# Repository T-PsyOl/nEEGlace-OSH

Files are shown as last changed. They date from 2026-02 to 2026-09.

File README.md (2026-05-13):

# nEEGlace-OpenHardware

nEEGlace open hardware
nEEGlace is an open hardware platform for studying neural activity in everyday
environments. It is designed to enable long-term, wearable EEG recordings
combined with rich contextual data, such as binaural audio, while remaining
compact, reproducible, and extensible.

The project is developed at the Translational Psychology Lab,
at the Department of Psychology at the Carl von Ossietzky Universität Oldenburg.

## Motivation

Understanding brain activity outside the laboratory is essential for studying
natural cognition, perception, and behavior. However, conventional EEG systems
are typically bulky, restrictive, and optimized for short, controlled
experiments. As a result, they are poorly suited for long-term or
ecologically valid recordings and often lack information about the sensory and
environmental context in which neural signals are recorded.

nEEGlace addresses these limitations by integrating ear-EEG with additional
contextual sensors into a neck-worn, wearable system that can be used in
real-world settings.

## Scientific Background

nEEGlace-OpenHardware builds on several stages of previous work on mobile,
neck-worn EEG systems for studying brain activity beyond the laboratory.

An early precursor was used in a long-term mobile ear-EEG study on auditory
attention in everyday life. In that study, a mobile EEG amplifier was attached
to headphones worn around the neck, which were also used for sound presentation.
Participants wore the setup for several hours while performing auditory oddball
tasks in the laboratory and during normal office routines. This work showed that
long-term mobile EEG recordings can be used to study auditory processing in
everyday settings.
The study can be found here:

[Hölle, D., Meekes, J., & Bleichner, M. G. (2021). Mobile ear-EEG to study
auditory attention in everyday life. *Behavior Research Methods*, 53,
2025–2036.](https://doi.org/10.3758/s13428-021-01538-0)

Based on this experience, the original nEEGlace system was developed as a more
integrated neck-worn platform. It combined a commercial, research-grade EEG
amplifier with a commercial neck speaker, creating a compact system for mobile
EEG recordings with integrated sound presentation and contextual audio
recording.

The original nEEGlace project is documented in the previous repository:

[https://github.com/T-PsyOl/neeglace](https://github.com/T-PsyOl/neeglace)

The associated hardware metapaper was published in the *Journal of Open
Hardware*:

[Bleichner, M. G., & Emkes, R. (2020). Building an Ear-EEG System by Hacking a
Commercial Neck Speaker and a Commercial EEG Amplifier to Record Brain Activity
Beyond the Lab. *Journal of Open Hardware*, 4(1).](https://doi.org/10.5334/joh.25)

This nEEGlace version was subsequently used in a study on smartphone-based
ear-EEG for investigating sound processing in everyday life. In that work,
participants were equipped with the nEEGlace, a smartphone-based recording setup, and microphones for recording
the acoustic environment. The study demonstrated how mobile EEG recordings can
be combined with contextual sound information to investigate neural responses
to sounds in more naturalistic conditions.

The study is described here:

[Hölle, D., & Bleichner, M. G. (2023). Smartphone-based
ear-electroencephalography to study sound processing in everyday life.
*European Journal of Neuroscience*, 58(7), 3671–3685.](https://doi.org/10.1111/ejn.16124)

The current nEEGlace-OpenHardware platform continues this line of work. Whereas
the earlier systems relied on adapting and integrating commercial components,
nEEGlace-OpenHardware is designed as a reproducible, modular, and extensible
open-hardware platform. It retains the central scientific aim of recording
neural activity together with contextual information in everyday environments,
while making the system easier to document, reproduce, modify, and further
develop.

## System Overview
nEEGlace is designed around a modular, 3D-printable casing that can be worn around
the neck. The casing houses the core components required for mobile EEG and
contextual audio recording and provides a reproducible mechanical platform for
integrating different hardware configurations.

The system includes:

- **A neck-worn casing** that can be 3D printed and adapted to house different
  hardware components and configurations.
- **Electrode connectors** for connecting ear-EEG electrodes, such as cEEGrids,
  or other EEG electrode arrangements.
- **An EEG acquisition system** for recording neural activity during mobile
  measurements.
- **An audio processing board** for real-time audio processing, event
  extraction, and event injection into the EEG data stream.
- **Binaural microphones** for recording the acoustic environment from the
  wearer’s perspective.
- **A battery unit** that powers all components for several hours of mobile
  operation.

The system is modular by design. Components such as the EEG system, audio board,
microphones, battery unit, connectors, and casing parts can be modified,
replaced, or reconfigured without redesigning the full platform. This allows
nEEGlace to serve as a general neck-worn hardware platform for mobile
neurophysiology and context-aware sensing, rather than as a fixed device tied to
one specific hardware setup.

## Repository Structure

This repository contains all components required to build, program, and use the
nEEGlace system:
- assets/ Media files, figures, and illustrations
- docs/ Background documentation and design rationale
- firmware/ Low-level firmware for embedded components
- hardware/ Hardware documentation (electronics, BMS, casing, wiring)
- manufacturing/ Manufacturing files and production-related information
- software/ User-facing software, analysis tools, and utilities
- test/ Hardware and software tests and validation scripts

Each folder contains its own README with more detailed documentation.

## Design Principles

nEEGlace follows a small set of guiding principles:

- **Open hardware**: schematics, layouts, and designs are shared
- **Modularity**: hardware and software components are loosely coupled
- **Wearability**: suitable for long-term use in everyday environments
- **Context awareness**: neural data is recorded together with relevant
  environmental information

## Project Status

nEEGlace is an active research and development project.
The hardware and software described here reflect the current prototype and may
evolve over time. Contributions, feedback, and replication efforts are welcome.

For details on specific components, please start with the corresponding
subfolder.

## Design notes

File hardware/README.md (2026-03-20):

# nEEGlace Hardware
This directory documents the complete hardware setup of the nEEGlace system.

The hardware integrates EEG acquisition, high-quality audio recording,
real-time processing, and battery-powered operation into a single wearable
device.

## System Overview

The nEEGlace hardware is built around the following core components:

- [Bela GEM Stereo](https://eu.shop.bela.io/products/bela-gem-stereo) for real-time audio and control
   - We originally used the Bela Mini; however, as it has been discontinued, we are transitioning to the Bela GEM Stereo.
- [OpenBCI Cyton (8-channel)](https://shop.openbci.com/products/cyton-biosensing-board-8-channel) or [Cyton + Daisy (16-channel)](https://shop.openbci.com/products/cyton-daisy-biosensing-boards-16-channel) for (ear)-EEG
- [Roland CS-10EM binaural microphones](https://proav.roland.com/de/products/proav_cs-10em/) for stereo audio
- **Battery Management System (BMS)** and rechargeable battery
- **Custom Bela Cape** for electrical integration
- **Wearable casing** and internal wiring

## Directory Structure

hardware/
├── BMS/
│   └── README.md
├── cape/
│   └── README.md
├── casing/
│   └── README.md
├── wiring/
│   └── README.md
└── README.md  ← you are here

Each subfolder documents one hardware module and its role in the overall system.

## Required Hardware Components

### 1. Processing and Control
- **Bela Gem Stereo**
  - Executes real-time audio and data acquisition code
  - Acts as the central control unit

- **Custom Bela Cape**
  - Interfaces Bela Mini with:
    - OpenBCI EEG amplifier
    - Roland CS-10EM microphones
    - Power system
  - Provides signal routing and mechanical mounting

### 2. EEG Acquisition
- **OpenBCI Cyton Biosensing Board (8-channel)**  
  *or*  
- **OpenBCI Cyton + Daisy Biosensing Boards (16-channel)**

- **EEG electrodes**
  - EEG electrodes
  - OpenBCI-compatible connectors and cables

### 3. Audio Acquisition
- **Roland CS-10EM binaural microphones**
  - In-ear stereo microphones
  - Connected to Bela Mini audio inputs

- **Audio cabling**
  - Stereo microphone cables

### 4. Power System
- **Rechargeable battery**
  - LiPo

- **Battery Management System (BMS)**
  - Battery charging
  - Electrical protection
  - Power distribution to Bela and peripherals

### 5. Wiring and Interconnection

### 6. Mechanical Components
- **nEEGlace casing**
  - Houses all electronic components
  - Designed for wearable, everyday use
- Fasteners and mounting elements

## Design Principles

The nEEGlace hardware follows these principles:

- **Open hardware**: all designs are shared and documented
- **Modularity**: individual components can be replaced or extended
- **Low-noise design**: separate EEG and audio signal paths
- **Wearability**: suitable for long-term, real-world recordings

## Status

This documentation reflects the current nEEGlace prototype.
Hardware components and interfaces may evolve as the project progresses.
Each submodule README documents its current state and known limitations.

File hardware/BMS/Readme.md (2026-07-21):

# <ins>nEEGlace – Battery Management System (BMS)</ins>

---

## Table of Contents

- [Overview](#overview)
- [Repository Structure & File Guide](#repository-structure--file-guide)
- [Hardware Overview](#hardware-overview)
- [Component Reference](#component-reference)
  - [Battery Connector](#battery-connector)
  - [HiLetgo Module Connectors](#hiletgo-module-connectors)
  - [Power Switch (S)](#power-switch-s)
  - [Charge-Detect MOSFET (SSI2301CDS-T1-E3)](#charge-detect-mosfet-ssi2301cds-t1-e3)
  - [LDO Regulator (MCP1700T-3302)](#ldo-regulator-mcp1700t-3302)
  - [Bela 5V Output Connector](#bela-5v-output-connector)
  - [3.3V OBCI Output Connector](#33v-obci-output-connector)
  - [Mic 3.3V Output Connector](#mic-33v-output-connector)
- [Power Architecture](#power-architecture)
- [Charge-Safety Logic — Why the MOSFET Matters](#charge-safety-logic--why-the-mosfet-matters)
- [Signal Routing & Design Rationale](#signal-routing--design-rationale)
- [Connector Pinouts](#connector-pinouts)
- [Layer Stack](#layer-stack)
- [Use Cases](#use-cases)
---

## Overview

The **nEEGlace BMS** is a single-layer-routed, two-layer PCB that sits between a single-cell Li-ion/Li-Po battery, a **HiLetgo** charge/boost breakout module, and the downstream **Bela** + **OpenBCI** electronics on the nEEGlace headset. It provides:

- **Battery input** with a physical power switch
- **Charge-state detection** that automatically disconnects the downstream system while the battery is charging (prevents brown-outs, ground loops, and noisy USB power from reaching sensitive analog inputs)
- **Regulated 5V output** to power the Bela cape directly from the HiLetgo module
- **Regulated 3.3V output** (via onboard LDO) for the OpenBCI board and the microphone bias input on the Bela Cape

This board is designed for:
- Portable / wearable EEG data acquisition (nEEGlace headset)
- Powering a Bela Cape + Bela embedded audio platform from battery
-  Safe co-operation with OpenBCI boards on a shared battery rail
-  Automatic charge-safe shutdown — no manual power cycling required when charging

---

## Repository Structure & File Guide

```
nEEGlace BMS/
│
├── Assembly files/                    # Production-ready fabrication package
│   └── PickAndPlace_PCB_nEEGlace_BMS_* #   Centroid/pick-and-place file for PCBA
│
├── Datasheets/                        # Component datasheets (LDO, MOSFET, HiLetgo, etc.)
│
├── BMS_PCB_Connections.pdf            # Wiring / interconnection reference
│                                      #   → How the BMS connects to Battery,
│                                      #     HiLetgo, Bela, and OpenBCI
│
├── Gerber_nEEGlace_BMS_PCB.zip         # Gerber + Excellon drill files
│                                      #   → Send to any PCB fab to order boards
│
├── OBJ_PCB_nEEGlace_BMS.zip            # 3D mechanical model (OBJ format)
│                                      #   → Use for enclosure design and
│                                      #     mechanical clearance verification
│
├── PCB_nEEGlace_BMS.json              # KiCad PCB layout (machine-readable)
│
├── PCB_nEEGlace_BMS.pdf               # Printable PCB layout (all layers)
│
├── nEEGlace_BMS_PCB.png               # Rendered 3D top-view image of the PCB
│
├── Schematic_nEEGlace_BMS.pdf          # Complete circuit schematic
│                                      #   → Primary reference for signal tracing,
│                                      #     net names, and component values
│
├── odb++_pcb_BMS.tgz                  # ODB++ manufacturing data (alternative to Gerbers)
│
└── Readme.md                          # This file
```

### Quick-Reference: Which File Do I Need?

| Goal | File to Use |
|---|---|
| Order bare PCBs | `Gerber_nEEGlace_BMS_PCB.zip` or `odb++_pcb_BMS.tgz` |
| Order fully assembled PCBs (PCBA) | `Assembly files/` folder |
| Understand the circuit | `Schematic_nEEGlace_BMS.pdf` |
| Wire the board into the nEEGlace system | `BMS_PCB_Connections.pdf` |
| Design an enclosure | `OBJ_PCB_nEEGlace_BMS.zip` |
| Visual reference during assembly | `nEEGlace_BMS_PCB.png` / `PCB_nEEGlace_BMS.pdf` |
| Source replacement parts | `Datasheets/` folder |

---

## Hardware Overview
Screenshot 2026-06-23 at 10 32 29 PM

**Board form factor:** Small wearable-friendly form factor for the nEEGlace headset
**Layer count:** 2 (signal + ground plane)
**Key active components:** 1× LDO regulator, 1× N-channel MOSFET, 1× SPDT/SPST power switch

---

## Component Reference

## <ins>Hardware Components</ins>

1. [3.7 V 6000 mAh Li-ion battery](https://www.reichelt.de/de/de/shop/produkt/ersatzakku_jbl_charge_li-po_6000_mah-248010)
2. [HiLetGo USB-C / USB-A charging and discharging board](https://www.amazon.de/HiLetgo-Discharging-Integrated-Interface-Compatible/dp/B0CDWT9295)
3. [MCP1700-330E low-dropout regulator (3.3 V)](https://www.mouser.de/ProductDetail/Microchip-Technology/MCP1700T-3302E-MB?qs=WWgnj3qycfnlJJhwyn%2Fifw%3D%3D)
4. [Schottky Diode(for unidirectional charge routing)](https://www.mouser.de/ProductDetail/Rectron/SR340-T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)
5. [MOSFET(for safety load-switching)](https://www.mouser.de/ProductDetail/Vishay-Semiconductors/SI2301CDS-T1-E3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)
6. 100 kΩ and 10 kΩ resistors (supporting the MOSFET circuit)
7. Decoupling capacitor on 5 V rail- 10u and 100uF.
8. Custom two-layer PCB
9. Ground vias for noise reduction
10. Through-hole pads for power connections (no pin headers)
11. [Slider switch](https://www.reichelt.com/de/en/shop/product/slide_switch_straight_pitch_2_54_1_x_on_off_on-105710)
12. [Cables](https://www.reichelt.com/de/en/shop/product/copper_wire_0_5mm_10m_black-404600)

> A compact battery management and power-distribution board for the **nEEGlace** wearable EEG system, providing charge-safe power switching, 5V regulation via a HiLetgo boost/charge module, and 3.3V LDO regulation for OpenBCI and Bela Cape microphone inputs.

### Battery Connector

- **Location:** Bottom-left of the board, labelled `Battery`
- **Type:** 2-pin connector (JST-style)
- **Signals:** Battery (+), Battery (−) / GND
- **Function:** Main single-cell Li-ion/Li-Po input to the system

The battery feeds the **HiLetgo** module through the power switch, and is also the source that gets recharged when the HiLetgo module is connected to USB-C.

---

### HiLetgo Module Connectors

There are **two connectors** dedicated to the HiLetgo charge/boost breakout module:

| Connector | Location | Function |
|---|---|---|
| `HiLetgo` | Right edge, lower | Carries raw battery (+/−) to the HiLetgo module's battery terminal |
| `HiLetgo 5V` | Right edge, middle | Returns the HiLetgo module's regulated **5V output** back onto the BMS board |

**Design rationale:** The HiLetgo module performs two jobs depending on its USB-C state:
- **Battery present, no USB-C:** boosts/regulates the battery voltage to a constant 5V output
- **USB-C connected:** charges the battery, while still passing 5V through if powered

Because the same 5V output pin is active in both states, the BMS must distinguish *which* state is active before letting that 5V propagate downstream — this is the job of the MOSFET (see below).

---

### Power Switch (S)

- **Location:** Centre of the board, labelled `Switch`
- **Type:** Through-hole 6-pin (likely SPDT slide or tactile latching) switch
- **Function:** Main system on/off control

When closed, the switch connects the battery to the HiLetgo module's battery input, enabling the boost/regulation path. When open, the entire downstream system (Bela, OpenBCI, mic bias) is unpowered regardless of charge state.

---

### Charge-Detect MOSFET (SSI2301CDS-T1-E3)

- **Location:** Centre-left, labelled `MOSFET`, package SOT-23-3P
- **Part:** SSI2301CDS-T1-E3 — N-channel logic-level MOSFET
- **Function:** Automatic charge-state power gating

```
HiLetgo 5V ──┬── [10kΩ] ──┐
             │            ├──► Gate (charge-detect node)
             └── [100kΩ] ─┘
                            │
                          MOSFET (G-D-S)
                            │
                  Drain ──► to LDO input / downstream 5V rail
                  Source ─► GND (when conducting to ground, system is held OFF)
```

- **Battery discharging (not charging):** the gate-bias network is referenced through the **10 kΩ** path, the MOSFET is **off** (or its drain path is held high), and 5V/3.3V flow normally to Bela, OpenBCI, and the mic bias.
- **Battery charging (USB-C connected to HiLetgo):** the gate-bias network switches to the **100 kΩ** path, pulling the MOSFET's gate to a state where its drain is shorted to **GND**, which collapses the downstream 5V rail and **forcibly powers down the entire system**.

**Design rationale:** Charging a Li-ion cell injects noisy, switching-regulator ripple onto the battery rail, and most USB power bricks are not clean enough for sensitive EEG/biosignal analog front-ends. Rather than relying on the user to remember to power off the headset before charging, this MOSFET network makes shutdown-while-charging **automatic and unconditional**.

---

### LDO Regulator (MCP1700T-3302)

- **Location:** Top-centre, labelled `LDO`, package SOT-89-3
- **Part:** MCP1700T-3302 — fixed 3.3V output, low quiescent current (~1.6 µA), low-dropout linear regulator
- **Input:** Regulated 5V from the HiLetgo module (gated through the MOSFET)
- **Output:** Clean 3.3V rail, distributed to:
  - `3.3V OBCI` connector — powers the OpenBCI board
  - `Mic 3.3V` connector — supplies microphone bias voltage to the Bela Cape's mic input

**Design rationale:** The MCP1700 was chosen for its very low quiescent current (critical for battery life in a wearable) and low dropout voltage, ensuring a stable 3.3V rail even as the upstream 5V sags slightly under load.

---

### Bela 5V Output Connector

- **Location:** Top-left, labelled `Bela 5V`
- **Type:** 2-pin connector
- **Signals:** 5V (+), GND
- **Function:** Delivers the gated 5V rail directly to the Bela embedded audio platform's `5V Input` connector (see the companion [Bela Cape](#) repository)

---

### 3.3V OBCI Output Connector

- **Location:** Top-right, labelled `3.3V OBCI`
- **Type:** 2-pin connector
- **Signals:** 3.3V (+), GND
- **Function:** Powers the OpenBCI biosignal acquisition board from the onboard LDO output

---

### Mic 3.3V Output Connector

- **Location:** Top-left, labelled `Mic 3.3V`
- **Type:** 2-pin connector
- **Signals:** 3.3V (+), GND
- **Function:** Supplies microphone bias voltage to the Bela Cape's L-Mic/R-Mic electret bias network (replacing or supplementing the Bela Cape's own VD2 rail, depending on system configuration)

---

## Power Architecture

```
Battery ──[Switch S]──► HiLetgo (battery terminal)
                              │
                              │  (boost/regulate when discharging,
                              │   charge battery when USB-C present)
                              ▼
                        HiLetgo 5V output
                              │
                              ▼
                 ┌── Charge-detect MOSFET gate network ──┐
                 │     10kΩ (discharging) / 100kΩ (charging)
                 ▼
        MOSFET drain-source gate
                 │
        ┌────────┴─────────┐
        │ Charging?         │
        │  YES → MOSFET pulls rail to GND → system OFF
        │  NO  → rail passes through → system ON
        └────────┬─────────┘
                  ▼
            Gated 5V rail
                  │
        ┌─────────┼─────────┐
        ▼                   ▼
   Bela 5V connector    LDO (MCP1700T-3302)
   (powers Bela cape)         │
                               ▼
                         Gated 3.3V rail
                               │
                  ┌────────────┴────────────┐
                  ▼                         ▼
           3.3V OBCI connector       Mic 3.3V connector
           (powers OpenBCI)          (Bela Cape mic bias)
```

**Ground plane:** A solid ground pour provides a common return path for the battery, HiLetgo, switch, MOSFET, LDO, and all downstream connectors, minimising ground bounce between the digital switch logic and the analog 3.3V mic-bias rail.

---

## Charge-Safety Logic — Why the MOSFET Matters

| HiLetgo State | Gate Bias Path | MOSFET State | Downstream 5V/3.3V | System Behaviour |
|---|---|---|---|---|
| Battery only (discharging) | 10 kΩ | Off / non-conducting to GND | Passes through normally | Bela, OpenBCI, and mic bias powered — **system ON** |
| USB-C connected (battery charging) | 100 kΩ | Drain pulled to GND | Collapsed to ~0V | All downstream rails de-energised — **system OFF** |

This means the nEEGlace headset **cannot be operated while its battery is charging** — a deliberate safety/noise-isolation choice rather than a limitation, since charging current and switching noise from most USB power sources would otherwise contaminate EEG and audio signal acquisition.

>  Confirm the exact gate-bias resistor values and MOSFET orientation against `Schematic_nEEGlace_BMS.pdf` before reproducing this board — the description above reflects the intended design behaviour.

---

## Signal Routing & Design Rationale

### Why Route 5V to Bela *Before* the LDO?

Bela's onboard audio codec has its own internal regulation and is designed to accept 5V directly, so routing the gated 5V rail straight to the `Bela 5V` connector avoids an unnecessary regulation stage and the associated efficiency loss.

### Why a Separate 3.3V Rail for OBCI and Mic Bias?

OpenBCI boards and electret microphone bias circuits are both sensitive to supply noise. Deriving both from the same clean MCP1700T LDO output — rather than tapping raw, less-regulated 5V — keeps both subsystems on a quiet, low-noise rail.

### Why Gate the Rail at the MOSFET Instead of at the Switch?

Using the manual switch alone cannot distinguish "battery discharging" from "battery charging" — both look like "switch closed" to the user. Placing the cutoff at the MOSFET, driven by the charge-state-dependent resistor network, makes the protection **automatic and independent of user action**.

---

## Connector Pinouts

> The table below is derived from the PCB silkscreen and 3D render inspection. **Always cross-reference with `Schematic_nEEGlace_BMS.pdf`** and `BMS_PCB_Connections.pdf` for confirmed pin assignments before wiring external hardware.

| Connector | Pin 1 | Pin 2 | Notes |
|---|---|---|---|
| Battery | Battery (+) | GND | Single-cell Li-ion/Li-Po input |
| HiLetgo | Battery (+) passthrough | GND | To HiLetgo module battery terminal |
| HiLetgo 5V | 5V (+) | GND | Return from HiLetgo regulated output |
| Bela 5V | 5V (+) gated | GND | To Bela `5V Input` connector |
| 3.3V OBCI | 3.3V (+) gated | GND | To OpenBCI power input |
| Mic 3.3V | 3.3V (+) gated | GND | To Bela Cape mic bias / VD2 domain |
| Switch (S) | Battery (+) in | Switched (+) out | Main power switch, see schematic for full 6-pin map |

---

## Layer Stack

| Layer | Colour in PCB Viewer | Role |
|---|---|---|
| F.Cu (Top) | Red | Power routing (battery, HiLetgo, switch, regulated rails) |
| B.Cu (Bottom) | Blue / dark blue | Ground plane + secondary routing |
| F.SilkS | White text | Component references, net labels |
| F.Courtyard | Outlines | Component keep-out boundaries |
| Edge.Cuts | Board outline | PCB boundary definition |

---

## Use Cases

### Wearable EEG + Audio Acquisition (nEEGlace)

Powers the full nEEGlace stack — Bela (audio/triggering), OpenBCI (EEG acquisition), and the Bela Cape's microphone front-end — from a single rechargeable battery, with automatic protection against operating the system while charging.

### Charge-Safe Battery Power for Bela Projects

Can be reused as a general-purpose charge-safe 5V/3.3V battery power supply for any Bela-based project that should never run while its battery is on charge.

### Combined Bio-signal + Audio Synchronisation

Pairs naturally with the companion **Bela Cape (Bela Gem Stereo)** board's D0/D1 trigger lines, enabling synchronised EEG and audio event marking from a single battery-powered, wearable platform.

---

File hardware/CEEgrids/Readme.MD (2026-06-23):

# CeeGrid Anschluss — cEEGrid-to-OpenBCI Connector Adapter

> A small passthrough adapter PCB that breaks out OpenBCI electrode channels to a Samtec connector, allowing **cEEGrid** ear-EEG electrode arrays to be plugged directly into an OpenBCI board.

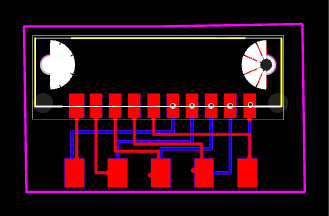
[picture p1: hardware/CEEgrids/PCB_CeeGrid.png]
PCB Layout


---

## Overview

The **CeeGrid Anschluss** ("Anschluss" = German for "connection") board is a simple two-sided breakout adapter. It has no active components — it exists purely to re-route OpenBCI's pin spacing/order to match the connector used on commercial **cEEGrid** electrode arrays, so the cEEGrid cable can be connected with a single plug instead of loose jumper wires.

---

## Repository Structure & File Guide

```
CeeGrid Anschluss/
│
├── Assembly files/              # Pick-and-place data for PCBA ordering
│   └── PickAndPlace_CeeGrid.csv
│
├── CeeGrid Anschluss.sch        # Schematic (KiCad)
├── CeeGrid Anschluss.brd        # PCB layout (KiCad)
├── Gerber_CEEgrids.zip          # Gerber + drill files — send to any PCB fab
├── PCB_CeeGrid.png              # Rendered top-view image of the PCB
└── Readme.md                    # This file
```

| Goal | File to Use |
|---|---|
| Order bare PCBs | `Gerber_CEEgrids.zip` |
| Order assembled PCBs (PCBA) | `Assembly files/` |
| Understand/edit the circuit | `CeeGrid Anschluss.sch` / `.brd` |
| Visual reference | `PCB_CeeGrid.png` |

---

## Connector Used

**Samtec MB1-120-01-F-S-02-SL** — 1.00 mm Mini Edge Card Socket with Guides

- Single-row edge-card socket, up to 50 pins, 1.00 mm pitch
- Includes card guides for easy, repeatable alignment when plugging in the cEEGrid cable's edge connector
- Current rating: 2.4 A max · Voltage rating: 250 VAC / 354 VDC max
- Accepts 0.031" (0.80 mm) and 0.062" (1.60 mm) thick edge cards

🔗 Buy / datasheet: [samtec.com/products/mb1-120-01-f-s-02-sl](https://www.samtec.com/products/mb1-120-01-f-s-02-sl)

---

## Hardware Overview

- **Top side:** Samtec MB1-120-01-F-S-02-SL edge card socket — the cEEGrid array's cable plugs straight into this
- **Bottom side (and mirrored on top):** Five **2×5 copper-pour pads**, sized for soldering the **male header pins coming from the OpenBCI board**
- **No actives, no passives** — purely a 1:1 (re-ordered) signal passthrough between the OpenBCI header pins and the Samtec connector pins

### Design Rationale

1. **OpenBCI side:** A 2×5 male header is soldered onto OpenBCI's electrode header pins.
2. **CeeGrid Anschluss board:** Solders directly onto those male pins via the 2×5 copper-pour footprints (present on both sides of the board so it can be mounted either way up).
3. **cEEGrid side:** A Samtec connector is soldered on top of the board, and the cEEGrid array's own cable simply plugs into it.

The internal routing (visible as the red/blue traces in the layout) re-maps each OpenBCI pin to the correct Samtec pin position, since the two connectors don't share the same pin order.

This turns a fiddly multi-wire connection into a **single plug-in connector**, reducing wiring errors and making it fast to swap cEEGrid arrays between sessions.

---

## Layer Stack

| Layer | Role |
|---|---|
| Top copper | Samtec connector pads + routing |
| Bottom copper | Mirrored 2×5 OpenBCI header pads + routing |
| Edge cuts | Board outline |

---

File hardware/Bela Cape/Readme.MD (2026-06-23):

# Bela Cape — Bela Gem Stereo

> A custom BeagleBone expansion cape for low-latency stereo audio I/O, dual-channel microphone input, digital event triggering, and sensor interfacing — built on the [Bela real-time audio platform](https://bela.io).

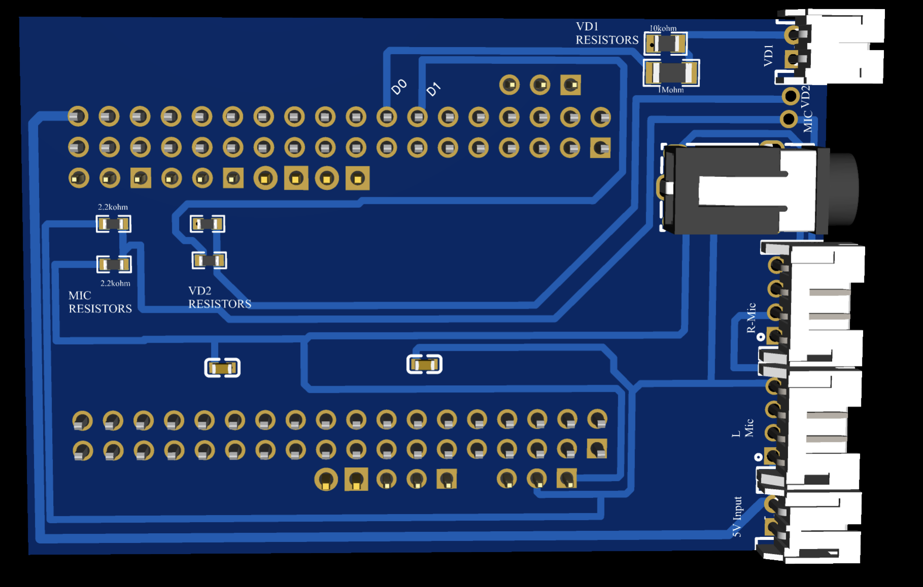
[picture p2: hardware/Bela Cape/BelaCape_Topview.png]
PCB Top View


---

## Table of Contents

- [Overview](#overview)
- [Repository Structure & File Guide](#repository-structure--file-guide)
- [Board Variants in This Repository](#board-variants-in-this-repository)
- [Hardware Overview](#hardware-overview)
- [Component Reference](#component-reference)
  - [BeagleBone Expansion Headers (P1 & P2)](#beaglebone-expansion-headers-p1--p2)
  - [3.5 mm Stereo Audio Jack](#35-mm-stereo-audio-jack)
  - [Right Microphone Input — R-Mic Connector](#right-microphone-input--r-mic-connector)
  - [Left Microphone Input — L-Mic Connector](#left-microphone-input--l-mic-connector)
  - [MIC Resistor Network (2× 2.2 kΩ)](#mic-resistor-network-2-22-kΩ)
  - [VD1 Resistor Network (10 kΩ + 1 MΩ)](#vd1-resistor-network-10-kΩ--1-mΩ)
  - [Digital Trigger Lines — D0](#digital-trigger-lines--d0--d1)
  - [Power Connectors (VD1, MIC VD2, 5V Input)](#power-connectors-vd1-vd2-mic-vd2-5v-input)
  - [Decoupling Capacitors](#decoupling-capacitors)
- [Power Architecture](#power-architecture)
- [Signal Routing & Design Rationale](#signal-routing--design-rationale)
- [Connector Pinouts](#connector-pinouts)
- [Layer Stack](#layer-stack)

---

## Overview

The **Bela Cape (Bela Gem Stereo)** is a two-layer PCB designed to expand the [Bela](https://bela.io) embedded audio platform with:

- **Stereo audio output** via a standard 3.5 mm TRS jack
- **Independent left and right microphone inputs** via dedicated JST-style edge connectors
- **Dual-channel microphone bias networks** for MEMS microphone PCB
- **High-impedance voltage divider networks** for biosignal or high-voltage sensor conditioning
- **Two digital trigger/sync lines (D0, D1)** for real-time event marking with external instruments
- **Dedicated power input (5V)** and multiple regulated supply rails (VD1, VD2) for clean analog operation
- **Full BeagleBone P8/P9 header passthrough** across two 36-pin expansion connectors

---

## Repository Structure & File Guide

```
Bela Cape/
│
├── PCB_Assembly_Files/            # Production-ready fabrication package
│   ├── BOM_BelaCape.csv           #   Bill of Materials (component list)
│   └── CPL_BelaCape.csv           #   Centroid/pick-and-place file for PCBA
│
├── 3D_BelaCape.step               # Full 3D mechanical model (STEP format)
│                                  #   → Use in FreeCAD, SolidWorks, KiCad, or
│                                  #     Fusion 360 for enclosure design and
│                                  #     mechanical clearance verification
│
├── BelaCape_Topview.png           # Rendered top-view image of the PCB
│
├── Bela_Cape_schematics.pdf       # Complete circuit schematic
│                                  #   → Primary reference for signal tracing,
│                                  #     net names, and component values
│
├── Gerber_BelaCape.zip            # Gerber + Excellon drill files
│                                  #   → Send to any PCB fab to order boards
│                                  #   → Tested with JLCPCB, PCBWay, Aisler
│
├── InteractiveBOM_BelaCape.html   # Browser-based interactive Bill of Materials
│                                  #   → Click any component to highlight its
│                                  #     location on the PCB layout image
│                                  #   → Invaluable during soldering & debugging
│
├── PCB_BelaCape.pdf               # Printable PCB layout (all layers)
│
├── PCB_BelaCape.png               # High-resolution PCB layout image
│
└── Readme.MD                      # This file
```

### Quick-Reference: Which File Do I Need?

| Goal | File to Use |
|---|---|
| Order bare PCBs | `Gerber_BelaCape.zip` |
| Order fully assembled PCBs (PCBA) | `PCB_Assembly_Files/` folder |
| Understand the circuit | `Bela_Cape_schematics.pdf` |
| Solder components yourself | `InteractiveBOM_BelaCape.html` |
| Design an enclosure | `3D_BelaCape.step` |
| Visual reference during assembly | `BelaCape_Topview.png` / `PCB_BelaCape.png` |

---

## Board Variants in This Repository

The KiCad project contains schematics for multiple sub-circuits, visible in the tab bar of the schematic editor:

| Schematic Tab | Description |
|---|---|
| `Bela_Gem_Stereo` | Top-level schematic — full board with stereo audio and dual mic |
| `Left_Mic` | Left microphone input sub-circuit (bias network, signal conditioning) |
| `Bela_Cape_Schematics` | Cape-level integration schematic (header connections, power routing) |

The **3D render** (`3D Bela_Gem_Stereo`) and **2D PCB layout** (`Bela_Gem_Stereo`) correspond to this repository's primary deliverable.

---

## Hardware Overview

---

## Component Reference

### BeagleBone Expansion Headers (P1 & P2)

The board carries **two dual-row 2×18 (36-pin) through-hole headers** mirroring the BeagleBone's P8 (top, P1) and P9 (bottom, P2) expansion connectors.

- **P1 (Top header):** Connects to BeagleBone P8 — GPIO, digital I/O, timers, SPI, UART
- **P2 (Bottom header):** Connects to BeagleBone P9 — analog inputs (ADC), I2C, power rails (3.3V, 5V, GND, VDD_ADC)

The square-pad pin markers at positions 1, 2 (and select sub-groups) of each header identify signal breakout groups — small JST or 0.1" connector clusters that route specific signals (L, R audio; Mic; VIN; GND; VD1; VD2) to edge-mounted connectors for cable attachment.

**Design rationale:** Full header passthrough allows this cape to be used as a **base layer in a multi-cape stack**, preserving all BeagleBone signals for additional boards above it.

---

### 3.5 mm Stereo Audio Jack

- **Location:** Right-centre edge of the board (physically dominant component)
- **Type:** PCB-mount 3.5 mm TRS stereo jack (vertical orientation, confirmed from 3D render)
- **Signals:** Left audio (L), Right audio (R), Ground (GND)
- **Optional:** TRRS variant can carry a 4th ring for microphone return

This jack provides the main **audio output** for the Bela system — suitable for headphones, amplified speakers, line-level recording equipment, or monitoring during a live performance.

**Design rationale:** The Bela audio codec outputs stereo at up to 96 kHz / 16-bit. A standard 3.5 mm jack provides universal compatibility with consumer and professional audio gear without additional adapters.

---

### Right Microphone Input — R-Mic Connector

- **Location:** Right edge, labelled `R-Mic` in the 3D render
- **Type:** 2-pin edge connector (JST-PH or equivalent)
- **Signals:** MIC signal (+), GND (−)
- **Bias:** Provided by the MIC Resistor Network (see below)

Connects a **right-channel MEMS microphone PCB ** or a pre-biased microphone module directly to the cape's analog front-end.

---

### Left Microphone Input — L-Mic Connector

- **Location:** Right edge, labelled `L-Mic` in the 3D render (below R-Mic)
- **Type:** 2-pin edge connector
- **Signals:** MIC signal (+), GND (−)
- **Bias:** Provided by the MIC Resistor Network (see below)

Mirrors the R-Mic connector for **left-channel microphone input**, enabling true stereo capture.

**Design rationale:** Separate physical connectors for each microphone channel allow independent placement of PCBs (e.g. spaced stereo, ORTF configuration) without a shared cable bundle.

---

### MIC Resistor Network (2× 2.2 kΩ)

- **Location:** Lower-left area, labelled `MIC RESISTORS.`
- **Components:** 4× SMD resistors — two 2.2 kΩ resistors per channel (Left and Right)
- **Function:** MEMS microphone PCB DC bias supply

Microphones contain an internal FET that requires a small DC bias current (typically 0.1–0.5 mA). The 2.2 kΩ resistors form a **bias-T network**, feeding DC bias from the VD2 supply rail through the resistor while allowing the AC audio signal to pass through to the ADC.

```
VD2 ──[2.2kΩ]──┬── MIC capsule (+) ──► to ADC input
                │
               [2.2kΩ]
                │
               GND
```

**Design rationale:** 2.2 kΩ is a standard value for electret biasing — low enough to supply adequate current, high enough to limit power dissipation. Separate networks per channel prevent left-right crosstalk through a shared bias node.

---

### VD1 Resistor Network (10 kΩ + 1 MΩ)

- **Location:** Top-right, labelled `VD1 RESISTORS`
- **Components:** 1× 10 kΩ SMD resistor + 1× 1 MΩ SMD resistor
- **Function:** High-ratio voltage divider to supply 33mV input to OpenBCI

This network creates a **100:1 voltage divider**:

```
Sensor signal ──[1MΩ]──┬──► to OpenBCI input (VD1 net)
                        │
                      [10kΩ]
                        │
                       GND
```

- Input impedance: ~1 MΩ (high — minimises loading on the source)
- Attenuation: ×0.01 (100:1 — scales a 3.3 V signal down to 33 mV, or a 180 mV biosignal to 1.8 mV)
- Output rail: `VD1`

---

### Digital Trigger Lines — D0 & D1

- **Location:** Upper-centre area, clearly labelled `D0` and `D1` on the PCB silkscreen
- **Signal level:** 3.3 V TTL (BeagleBone GPIO)
- **Drive capability:** Driven directly by BeagleBone PRU (Programmable Real-time Unit) for sub-microsecond latency
- **Routed to:** Both the P1 header passthrough and a dedicated breakout group

These are **event synchronisation/stimulus trigger outputs**. The Bela PRU can toggle D0 or D1 with nanosecond-scale jitter, making them suitable for:

| Application | How D0/D1 Is Used |
|---|---|
| EEG research | Pulse marks stimulus onset in the EEG data stream |

---

### Power Connectors (VD1, VD2, MIC VD2, 5V Input)

All visible on the right edge of the board in the 3D render:

| Connector Label | Location | Function |
|---|---|---|
| `VD1` | Top-right edge | Regulated supply output for VD1 domain (or input from external regulator) |
| `VD2` | Right edge (upper) | Regulated supply for VD2 / analog front-end domain |
| `MIC VD2` | Right edge | Dedicated supply feed to microphone bias resistors from VD2 rail |
| `5V Input` | Bottom-right edge | **Main power input** — 5 V DC supply for the entire cape |

The `5V Input` connector allows the cape to be **powered independently** from the BMS 5V supply, which is important when driving external microphone capsules and analog conditioning circuits that demand cleaner, more stable power than USB can reliably provide.

**Design rationale:** Separating the microphone supply (`MIC`) from 5V and from Bela's 3.3V input prevents DSP switching noise from coupling into the sensitive microphone bias path — a common source of audio artefacts in embedded audio systems.

---

### Decoupling Capacitors

- **Location:** Two SMD capacitors visible in the mid-board area (white-outlined rectangular pads in the 3D render)
- **Type:** Likely 100 nF (0.1 µF) ceramic SMD, standard 0402 or 0603 footprint
- **Function:** High-frequency power supply decoupling

Placed along the main signal routing channels, these capacitors:
- Filter switching noise from the BeagleBone's digital logic from coupling into analog paths
- Provide local charge reservoirs to suppress voltage droops during rapid current demands
- Reduce ground bounce on the shared power rails

Additional smaller decoupling capacitors are present adjacent to the VD1, VD2, and MIC resistor networks (visible as smaller gold pads throughout the board).

---

## Power Architecture

```
External 5V ──► [5V Input connector]
                        │
                        ├──► VIN rail (distributed to headers, P9.5/P9.6)
                        │
                        ├──► [Regulator or divider] ──► VD1 rail ──► VD1 connector
                        │                                              VD1 resistor network
                        │
                        └──► [Regulator or divider] ──► VD2 rail ──► VD2 connector
                                                                   
```

> The exact regulation topology (LDO, switching, or passive) is confirmed in `Bela_Cape_schematics.pdf`.

**Ground plane:** The entire bottom copper layer acts as a continuous ground plane, providing a low-impedance return path for all signals and acting as an EMI shield between the two layers.

---

## Signal Routing & Design Rationale

### Why Separate VD1 and VD2 Domains?

Analog circuits are highly sensitive to supply noise. By splitting the supply into two independently decoupled domains:
- **VD1** serves the high-impedance sensor/divider path (quieter, high-Z load)
- **VD2** serves as another set of resistor divider circuit, if the user wants to use it for different onset detection/ event marking. 

This prevents the microphone bias current transients from modulating the sensor reference voltage on VD1.

### Why a Solid Ground Plane?

The blue bottom layer (B.Cu) is a **solid copper pour tied to GND**. This:
- Minimises return path inductance for high-frequency signals
- Shields analog signals from digital switching noise emitted by the BeagleBone's processor
- Reduces crosstalk between the left and right microphone channels
- Improves audio signal-to-noise ratio (SNR)

### Trace Width Strategy

- **Wide red traces** (top layer): Power rails (VIN, VD1, VD2, GND connections) — wider traces lower DC resistance and handle higher current
- **Narrow traces**: Audio signal lines (L, R, MIC), digital lines (D0, D1) — routed away from power to minimise interference

### Why Edge Connectors for Mic and Power?

The R-Mic, L-Mic, VD1, VD2, MIC VD2, and 5V Input are all mounted on the **right board edge** — this layout keeps all external cable connections in one accessible area, allows the cape to sit flush in a rack or enclosure, and prevents cables from interfering with the BeagleBone's USB and Ethernet ports on the opposite end.

---

## Connector Pinouts

> The table below is derived from PCB labels and 3D render inspection. **Always cross-reference with `Bela_Cape_schematics.pdf`** for confirmed pin assignments before wiring external hardware.

### Right-Edge Connectors (top to bottom)

| Connector | Pin 1 | Pin 2 | Notes |
|---|---|---|---|
| VD1 | VD1 (+) | GND | Regulated supply |
| VD2 | VD2 (+) | GND | Regulated supply |
| MIC VD2 | MIC VD2 (+) | GND | Mic bias supply |
| Audio Jack | L (tip) | R (ring) + GND (sleeve) | 3.5mm TRS |
| R-Mic | MIC signal | GND | Right capsule |
| L-Mic | MIC signal | GND | Left capsule |
| 5V Input | 5V (+) | GND | Main power in |

### BeagleBone Header — Key Signals (P9 / P2)

| P9 Pin | Signal | Cape Usage |
|---|---|---|
| P9.1–2 | GND | Ground |
| P9.3–4 | 3.3V | Logic supply |
| P9.5–6 | 5V | VIN |
| P9.33 | AIN4 | ADC input (VD1 divider output) |
| P9.35–40 | AIN0–5 | ADC inputs for sensors/mic |

> Full P8/P9 pin mapping: refer to the [BeagleBone Black System Reference Manual](https://github.com/beagleboard/beaglebone-black/wiki/System-Reference-Manual).

---

## Layer Stack

| Layer | Colour in PCB Viewer | Role |
|---|---|---|
| F.Cu (Top) | Red | Signal routing, power distribution |
| B.Cu (Bottom) | Blue | Solid GND plane + secondary routing |
| F.SilkS | White text | Component references, net labels |
| F.Courtyard | Yellow outlines | Component keep-out boundaries |
| Edge.Cuts | Board outline | PCB boundary definition |

---

### Binaural / Stereo Microphone Recording

Connect MIC PCBs to L-Mic and R-Mic for real-time binaural audio capture. Bela's 44.1/48 kHz ADC with < 1 ms round-trip latency enables live processing (convolution reverb, beamforming, spatial audio).

### Analog Sensor Interfacing

Use the VD1 high-impedance divider (10 kΩ / 1 MΩ) to connect sensors that output signals above the BeagleBone's ADC range (0–1.8 V), including piezoelectric transducers, photovoltaic cells, or EEG front-end outputs.

---

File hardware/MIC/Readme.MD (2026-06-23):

# MIC PCB — MEMS Microphone Amplifier Module

> A compact, high-performance MEMS microphone front-end for the [nEEGlace](https://github.com/nEEGlace-OSH) open-source wearable EEG necklace. Captures acoustic context with an ultra-high dynamic range MEMS capsule and conditions its differential output through a precision zero-drift op-amp, delivering a clean single-ended analog signal to the nEEGlace acquisition system.

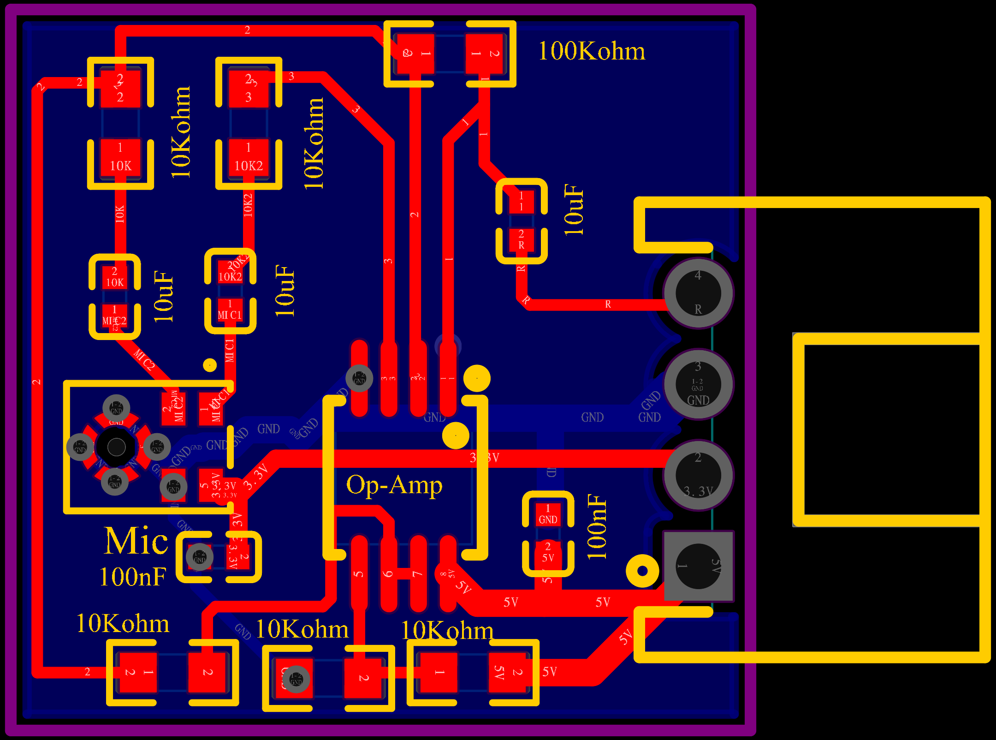
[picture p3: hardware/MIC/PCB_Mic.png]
PCB Layout


---

## Table of Contents

- [Overview](#overview)
- [Repository Structure & File Guide](#repository-structure--file-guide)
- [Hardware Overview](#hardware-overview)
- [Key Specifications](#key-specifications)
- [Component Reference](#component-reference)
  - [MEMS Microphone — ICS-40638 (TDK InvenSense)](#mems-microphone--ics-40638-tdk-invensense)
  - [Operational Amplifier — MAX74810 (Analog Devices / Maxim)](#operational-amplifier--max74810-analog-devices--maxim)
  - [Gain Resistors (10 kΩ × 4)](#gain-resistors-10-kω--4)
  - [Feedback Resistor (100 kΩ)](#feedback-resistor-100-kω)
  - [AC Coupling Capacitors (10 µF × 3)](#ac-coupling-capacitors-10-µf--3)
  - [Output Connector (4-pin)](#output-connector-4-pin)
- [Circuit Architecture](#circuit-architecture)
  - [Stage 1 — MEMS Microphone Output](#stage-1--mems-microphone-output)
  - [Stage 2 — Differential-to-Single-Ended Conversion & Amplification](#stage-2--differential-to-single-ended-conversion--amplification)
  - [Gain Calculation](#gain-calculation)
  - [Frequency Response](#frequency-response)
  - [Noise Analysis](#noise-analysis)
- [Power Architecture](#power-architecture)
- [Signal Routing & Design Rationale](#signal-routing--design-rationale)
- [Connector Pinout](#connector-pinout)
- [Layer Stack](#layer-stack)

---

## Overview

The **MIC PCB** is a self-contained MEMS microphone amplifier module developed as part of the **nEEGlace** open-source wearable EEG necklace project. It captures acoustic context using the **TDK InvenSense ICS-40638** — an analog MEMS microphone with an ultra-high 138 dB SPL acoustic overload point and 63 dB SNR — then amplifies the differential output through the **Analog Devices MAX74810**, a precision dual-channel zero-drift op-amp with 5.8 nV/√Hz input noise.

Together, these components form a microphone front-end with exceptional dynamic range and noise performance, designed specifically for wearable neurotechnology applications where acoustic context must be captured alongside EEG signals in noisy, real-world environments.

**Why these components matter for nEEGlace:**
- The ICS-40638's 138 dB AOP means the module survives loud environments (concerts, transport, labs with ventilation noise) without clipping — preserving the acoustic event markers used to align EEG epochs
- The MAX74810's zero-drift architecture eliminates DC offset drift over temperature — critical for a wearable device whose operating temperature changes as it warms against the user's skin
- The integrated EMI filters on both ICs provide robustness against the RF interference from the nEEGlace's wireless communication components

---

## Repository Structure & File Guide

```
hardware/MIC/
│
├── Assembly files/                  # Production-ready fabrication package
│   ├── BOM_Mic_PCB.csv              #   Bill of Materials (component list with part numbers)
│   └── PickAndPlace_Mic_PCB.csv     #   Centroid / pick-and-place file for PCBA
│
├── 3D_Mic.step                      # Full 3D mechanical model (STEP format)
│                                    #   → Use in FreeCAD, SolidWorks, KiCad, or
│                                    #     Fusion 360 for enclosure and wearable
│                                    #     necklace housing design
│
├── Gerber_Mic_PCB.zip               # Gerber + Excellon drill files
│                                    #   → Send to any PCB fab to order bare boards
│
└── PCB_Mic.png                      # High-resolution PCB layout image
```

### Quick-Reference: Which File Do I Need?

| Goal | File |
|---|---|
| Order bare PCBs | `Gerber_Mic_PCB.zip` |
| Order fully assembled PCBs (PCBA) | `Assembly files/` folder |
| Solder components yourself | `Assembly files/BOM_Mic_PCB.csv` |
| Design an enclosure / wearable housing | `3D_Mic.step` |
| Visual reference during assembly | `PCB_Mic.png` |

> **Note:** A schematic PDF and Interactive BOM (ibom.html) are not yet present in this directory — see [Recommended Additions](#recommended-additions-for-research-use). These are the two most important missing documents for anyone who wants to understand or reproduce this design.

---

## Hardware Overview

## Component Reference

### MEMS Microphone — ICS-40638 (TDK InvenSense)

- **Location:** Bottom-left, large multi-pad circular footprint labelled `Mic`
- **Manufacturer:** TDK InvenSense
- **Part number:** ICS-40638
- **Package:** 5-terminal LGA, 3.50 × 2.65 × 0.98 mm, bottom-port
- **Supply:** 3.3 V (within the 1.52–3.63 V operating range)
- **Current:** 170 µA typical

**What makes this a MEMS microphone (not electret):**

Unlike a traditional electret condenser capsule, the ICS-40638 integrates three components into a single silicon package:
1. **MEMS microphone element** — a microfabricated silicon diaphragm and backplate, acting as a pressure-sensitive capacitor
2. **Impedance converter** — an internal circuit that buffers the extremely high-impedance MEMS element output
3. **Differential output amplifier** — outputs two complementary signals (MIC+ and MIC−) for noise-immune signal transmission

Because the ICS-40638 has an **internal impedance converter and output amplifier**, it does **not** require an external bias resistor network — a key difference from traditional electret capsules. The 3.3 V supply powers the internal circuitry directly via the VDD pin; no external biasing components are needed.

**Bottom-port assembly note:**

The ICS-40638 is a **bottom-port** microphone — the acoustic port faces down, through a hole in the PCB. When assembling:
- A sound port hole (0.5–1.0 mm diameter recommended) must be present in the PCB beneath the mic footprint
- Do **not** apply solder paste over the sound hole
- Align the package's port hole with the PCB hole precisely during pick-and-place

**Datasheet:** [ICS-40638 Datasheet — TDK InvenSense](https://invensense.tdk.com/download-pdf/ics-40638-datasheet/)

---

### Operational Amplifier — MAX74810 (Analog Devices / Maxim)

- **Location:** Centre of board, SOIC-8 package, labelled `Op-Amp`
- **Manufacturer:** Analog Devices (formerly Maxim Integrated)
- **Part number:** MAX74810
- **Package:** SOIC-8 (8-pin, 1.27 mm pitch SMD)
- **Supply:** 5 V single supply (within 4.5–50 V operating range)

**Why the MAX74810 is the right choice here:**

The MAX74810 is a **zero-drift (chopper-stabilised)** op-amp — its internal architecture continuously corrects its own input offset voltage using a 4.8 MHz chopping clock. This means:

- **No DC offset drift:** Offset voltage stays at ≤ 7 µV regardless of temperature, ageing, or supply variation. For a wearable device cycling between ambient and skin temperature, this eliminates baseline wander in the amplified microphone signal.
- **1/f noise elimination:** The chopping technique modulates low-frequency (flicker) noise to 4.8 MHz and then filters it out — leaving only the 5.8 nV/√Hz broadband noise floor. At audio frequencies, this is extremely clean.
- **EMI immunity:** Integrated 200 Ω series input resistors + common-mode capacitors at the input form a built-in EMI filter — protecting the sensitive front-end from the wireless transceiver and EEG amplifier clocks on the nEEGlace main board.
- **Rail-to-rail output:** Full output swing on a 5 V supply maximises dynamic range before ADC clipping.
- **Wide supply range (4.5–50 V):** The 5 V supply here is well within the comfortable operating range, leaving voltage headroom margin.

**Datasheet:** [MAX74810 — Analog Devices](https://www.analog.com/en/products/MAX74810.html)

---

### Gain Resistors (10 kΩ × 4)

- **Location:** Upper-left area
- **Designators:** `10K` (×2, left column, net `MIC C2`) + `10K2` (×2, right column, net `MIC C1`)
- **Package:** SMD 0402 or 0603

These four resistors serve two distinct roles:

**Role 1 — Gain setting (R_gain in feedback network):**
In the non-inverting amplifier configuration:
```
Gain = 1 + (R_feedback / R_gain) = 1 + (100kΩ / 10kΩ) = 11×
```

**Role 2 — Virtual mid-rail bias (for each differential channel):**
The ICS-40638 outputs two complementary signals biased at VDD/2 (≈ 1.65 V on a 3.3 V supply). The 10 kΩ resistors set the op-amp's input bias point to match this mid-rail reference, ensuring the amplifier operates in the centre of its linear range on a single 5 V supply.

Having two 10 kΩ resistors per channel (10K and 10K2) also forms a matched pair for the two differential input legs of the op-amp — the symmetry minimises common-mode error and improves CMRR.

**Design rationale:** 10 kΩ is the standard recommendation from the MAX74810 datasheet to minimise offset voltage error due to input bias current (V_OS_error = I_B × R_source; lower R reduces this). It also keeps the gain network impedance low enough to avoid susceptibility to parasitic capacitance at audio frequencies.

---

### Feedback Resistor (100 kΩ)

- **Location:** Top-centre, labelled `100Kohm`
- **Package:** SMD 0402 or 0603
- **Function:** Sets the closed-loop gain of the amplifier in conjunction with the 10 kΩ gain resistors

```
Gain (Av) = 1 + (R_feedback / R_gain)
           = 1 + (100,000 / 10,000)
           = 11×
           ≈ 20.8 dB
```

This resistor sits in the negative feedback path from the op-amp output back to the inverting input (−), closing the feedback loop that stabilises and defines gain.

**Design rationale:** The MAX74810 datasheet recommends setting R_feedback = 10 kΩ to minimise offset; here the 100 kΩ value was chosen to achieve 11× gain, prioritising signal amplitude over absolute minimum offset. The MAX74810's extremely low native offset (7 µV max) means the additional offset contribution from the 100 kΩ feedback impedance remains negligible (50 pA × 100 kΩ = 5 µV) — well within the ADC's resolution.

The resulting gain-bandwidth product consumption at 11×:
```
f_-3dB = GBW / Av_closed = 2.7 MHz / 11 ≈ 245 kHz
```
This exceeds the 20 kHz audio band by more than an order of magnitude — no bandwidth limitation in the audible range.

---

### AC Coupling Capacitors (10 µF × 3)

Three 10 µF SMD capacitors handle AC coupling at different points in the signal chain:

| Position | Net | Function |
|---|-----|---|
| Left column (MIC C1) | MIC1 signal path | Blocks DC bias from ICS-40638 output (+), passes audio |
| Left column (MIC C2) | MIC2 signal path | Blocks DC bias from ICS-40638 output (−), passes complementary audio |
| Right side (near connector) | Op-amp output / supply | Output AC coupling or supply decoupling at the connector |

**Why AC coupling is essential with the ICS-40638:**

The ICS-40638's differential outputs are biased at VDD/2 ≈ 1.65 V DC. Without AC coupling, this 1.65 V DC offset would appear at the op-amp output as 1.65 V × 11 = 18.15 V — far exceeding the 5 V supply and saturating the amplifier entirely. The 10 µF capacitors block this DC, passing only the AC audio signal:

```
ICS-40638 MIC+ ──[10µF]──► Op-Amp Non-inv. (+)
ICS-40638 MIC− ──[10µF]──► Op-Amp Inv. (−) [via gain network]
```

**High-pass filter cutoff:**
```
f_cutoff = 1 / (2π × R × C)
          = 1 / (2π × 10,000 × 0.00001)
          ≈ 1.6 Hz
```

This cutoff is well below the ICS-40638's own 35 Hz lower limit, so the coupling capacitors introduce no additional bandwidth restriction. The effective system low-frequency cutoff is determined by the MEMS microphone (35 Hz), not the coupling caps.

**Design rationale:** 10 µF was chosen to achieve a low cutoff without using physically large electrolytic capacitors. Using SMD ceramic or tantalum 10 µF in 0603 or 0805 package keeps the board compact — essential for a wearable module.

---

### Output Connector (4-pin)

- **Location:** Right edge, 4-pin through-hole header
- **Connects to:** nEEGlace main acquisition board or Bela Cape `R-Mic`/`L-Mic` connectors

| Pin | Label | Signal | Direction |
|-----|---|---|---|
| 4 | R | Amplified audio output (Right channel) | Output |
| 3 | GND | Ground | Common |
| 2 | 3.3V | 3.3 V supply | Input (from host) |
| 1 | 5V | 5 V supply for op-amp | Input (from host) |

The host board supplies both 3.3 V (for the ICS-40638) and 5 V (for the MAX74810) to the module through this connector, keeping the MIC PCB free of its own voltage regulators — minimising component count and board area.

---

## Circuit Architecture

### Stage 1 — MEMS Microphone Output

```
                    ┌─────────────────────────────────────┐
                    │         ICS-40638                    │
                    │                                      │
3.3V ──────────────►│ VDD                                  │
                    │         MIC+ (≈ VDD/2 + audio/2) ──►│──[10µF]──► to Op-Amp (+)
         [Sound]──► │ MEMS element + impedance converter   │
                    │         MIC− (≈ VDD/2 − audio/2) ──►│──[10µF]──► to Op-Amp (−)
GND ───────────────►│ GND                                  │
                    └─────────────────────────────────────┘
```

The ICS-40638 outputs a **differential pair** — MIC+ and MIC− are complementary, each carrying half the audio signal amplitude with opposite polarity around a VDD/2 ≈ 1.65 V DC midpoint. This differential signalling provides:
- Common-mode noise rejection (any noise picked up by both lines cancels at the op-amp differential input)
- Double the signal amplitude compared to a single-ended output (improves SNR)
- Enhanced RF immunity — matching the ICS-40638's own built-in RF immunity enhancement

### Stage 2 — Differential-to-Single-Ended Conversion & Amplification

```
MIC+ ──[10µF]──────────────────────────────────────────► (+) ─┐
                                                                │  MAX74810
MIC− ──[10µF]──[10K gain resistor]──────────────────► (−) ─┤  Channel A  ├──► R output
                                                                │            │
                               GND ──[10K bias]─────────► (+) │  └─[100K]──┘ (feedback)
                                                               └─────────────────────────
```

The MAX74810 Channel A amplifies the difference between MIC+ and MIC−, rejecting common-mode noise. Channel B of the dual op-amp may buffer the 3.3V/2 virtual mid-rail reference, or handle a second microphone channel (MIC2) — confirm from the schematic PDF.

### Gain Calculation

```
Gain (Av) = 1 + (R_feedback / R_gain)
           = 1 + (100 kΩ / 10 kΩ)
           = 11×  ≈ 20.8 dB
```

**Expected output amplitudes:**

The ICS-40638 has −43 dBV sensitivity at 1 Pa (94 dB SPL), meaning its differential output is approximately 7 mV peak at 1 Pa:

| Sound level | Mic output (differential) | After 11× gain | Note |
|---|---|---|---|
| 40 dB SPL (quiet room) | ~0.07 mV | ~0.77 mV | ADC-readable |
| 60 dB SPL (conversation) | ~0.7 mV | ~7.7 mV | Comfortable level |
| 80 dB SPL (busy street) | ~7 mV | ~77 mV | Good ADC range |
| 100 dB SPL (loud music) | ~70 mV | ~770 mV | Well within 5V supply |
| 138 dB SPL (AOP limit) | ~565 mV | ~6.2 V | Clipped at supply — AOP is device limit |

At the operating supply of 5 V with rail-to-rail output, the MAX74810 saturates at ~5 V output. The ICS-40638's own AOP (138 dB) sets the ultimate input limit, not the amplifier — a well-matched design decision.

### Noise Analysis

**System input-referred noise (estimated):**

The dominant noise source at audio frequencies is the MAX74810's voltage noise (5.8 nV/√Hz), as the ICS-40638's internal amplifier presents a low-impedance output that does not contribute significantly to thermal noise at the op-amp input.

```
Output noise density ≈ 5.8 nV/√Hz × 11 (gain) = 63.8 nV/√Hz

Integrated noise (20 Hz – 20 kHz bandwidth):
  = 63.8 nV/√Hz × √(20,000 − 20)
  = 63.8 nV/√Hz × 141.4 Hz^0.5
  ≈ 9.0 µV RMS at output

Input-referred:
  = 9.0 µV / 11 ≈ 0.82 µV RMS
```

This is well below the ICS-40638's own noise floor (63 dB SNR → ~0.35 mV RMS noise at 1 Pa, 94 dB SPL), meaning the MAX74810 adds negligible noise — the system noise is dominated by the microphone, as intended.

---

## Power Architecture

```
5V Input (pin 1 connector)
    │
    └──► MAX74810 V+ (pin 8, SOIC-8)
         Rail-to-rail output stage
         Single-supply, ground-sensing input

3.3V Input (pin 2 connector)
    │
    └──► ICS-40638 VDD
         Powers MEMS element, impedance converter,
         and internal differential output amplifier

GND (pin 3 connector)
    └──► MAX74810 V− (pin 4)
         ICS-40638 GND
         Decoupling cap returns
         Solid ground plane (bottom copper layer)
```

**Why two separate supply voltages:**

- **3.3 V for ICS-40638:** The MEMS mic operates between 1.52–3.63 V; 3.3 V is the standard logic rail on the nEEGlace system, providing a stable, clean supply with no additional regulation needed. Using a voltage within the MEMS mic's rated range (rather than the maximum) also reduces the quiescent current slightly.

- **5 V for MAX74810:** Running the op-amp on 5 V rather than 3.3 V provides a larger output voltage swing headroom. With an 11× gain and the ICS-40638's mid-rail bias at 1.65 V, the amplified signal can swing ±(1.65 × 11) V before hitting the rails — on 5 V, the MAX74810's rail-to-rail output allows the full 0–5 V range, giving approximately 2.5 V of headroom above and below the output bias point.

**Power decoupling:** The ICS-40638 datasheet recommends a 0.1 µF ceramic capacitor placed as close as possible to its VDD pin. This is provided by one of the 10 µF capacitors on the board, which also covers the lower-frequency decoupling requirement. Additional smaller decoupling (100 nF) is recommended in any revised layout.

---

## Signal Routing & Design Rationale

### Why a Dedicated Daughter Board?

Isolating the MEMS microphone front-end onto a separate module rather than integrating it into the nEEGlace main PCB provides:

- **Acoustic placement flexibility:** The microphone module can be positioned on the necklace at the point of best acoustic capture (e.g. front-centre, close to the throat) independently of the main electronics PCB
- **Electrical isolation from digital noise:** The ICS-40638 and MAX74810 are both sensitive to supply noise. Physical separation from the BeagleBone/microcontroller and EEG front-end reduces coupling of switching noise into the audio signal path
- **Modularity:** Upgrade from mono to stereo by adding a second MIC PCB, or swap to a different MEMS capsule without redesigning the main board
- **Thermal separation:** Wearable devices warm unevenly; isolating the mic module allows it to reach thermal equilibrium independently of the main processor's heat dissipation

### Ground Plane

The blue bottom copper layer is a **solid GND plane**, which:
- Provides a low-inductance return path for the 170 µA ICS-40638 supply current
- Shields the nV-level MEMS output signals from radiated EMI generated by the nEEGlace wireless components
- Reduces 50/60 Hz hum pickup — the MAX74810's PSRR of −81 dB already rejects most supply-borne hum, but the ground plane prevents it from coupling via the input pins

### Compact Layout

Resistors and capacitors are clustered tightly around the MAX74810 to keep the signal path between the ICS-40638 output and the op-amp input as short as possible. Long traces on these high-impedance signal nodes act as antennas; minimising their length directly reduces noise pickup. The ICS-40638 should be as close to the op-amp input pins as the coupling caps allow.

---

## Connector Pinout

### Output Connector (4-pin, right edge)

| Pin | Signal | Direction | Voltage | Notes |
|-----|---|---|---|---|
| 1 | 5V | Input | 5.0 V | Op-amp supply — from host board |
| 2 | 3.3V | Input | 3.3 V | MEMS mic supply — from host board |
| 3 | GND | Common | 0 V | Ground reference |
| 4 | R | Output | 0–5 V AC | Amplified audio, right channel |

Connect to the nEEGlace main board MIC header, or to the Bela Cape's `R-Mic` / `L-Mic` connectors with signal on pin 4 and power on pins 1–2.

---

## Layer Stack

| Layer | Colour in PCB Viewer | Role |
|---|---|---|
| F.Cu (Top) | Red | Signal routing, component pads, power traces |
| B.Cu (Bottom) | Blue | Solid GND plane |
| F.SilkS | Yellow labels | Component values and net names |
| F.Courtyard | Yellow outlines | Component keepout boundaries |
| Edge.Cuts | Purple border | PCB boundary |

---

### Post-Assembly Test

```
1. Apply 5V between connector pin 1 and pin 3 (GND)
2. Apply 3.3V between connector pin 2 and pin 3 (GND)
3. Verify: current draw ~170 µA on 3.3V rail (ICS-40638 quiescent)
4. Monitor connector pin 4 (R) with oscilloscope:
   - DC level: ~VDD/2 × gain bias point (check vs. schematic)
   - Speak or tap 30 cm from mic: expect 10–100 mV AC swing for speech
5. Check for oscillation at 4.8MHz (MAX74810 chopping clock) — should be
   invisible at audio frequencies due to internal filtering
```

---

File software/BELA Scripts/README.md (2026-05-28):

# Audio Event Detection for nEEGlace

This folder contains the current audio event detection code for the nEEGlace prototype.

The general goal is to use microphone input to detect acoustic events in real time and generate markers that can be synchronized with EEG or other physiological recordings. 
In the current implementation, stereo microphone input is acquired by the Bela board. The audio signal is processed online, and an event marker is generated when the signal energy exceeds a predefined threshold.

At this stage, the implementation should be understood as a simple baseline detector. It demonstrates the basic processing pipeline from microphone input to event marker output, but it is not yet a full audio event classifier.

## Concept

The intended processing chain is:

```text
Stereo microphone input
        ↓
Bela audio acquisition
        ↓
Buffer-based audio processing
        ↓
Event detection
        ↓
Digital trigger output
        ↓
Synchronization with EEG / physiological data
```

The broader motivation is to add acoustic context to nEEGlace recordings. In real-world EEG recordings, it is often important to know when relevant sounds occurred in the environment. 
Detecting such events can help annotate recordings, identify time points of interest, and relate neural activity to events in the acoustic scene.

## Current implementation

The current script implements a simple energy-based onset detector.

Audio is read from the Bela audio inputs. Although both left and right microphone channels are acquired and visualized, the current detection logic uses one input channel for event detection. 
Samples are stored in a circular buffer. After a defined hop size, the energy of the current buffer is calculated as the mean squared amplitude of the samples.

If the energy exceeds a predefined threshold and the detector is not in its refractory period, an onset is detected. 
The script then activates a digital output pin for a short duration. This digital pulse can be used as an event marker.

The basic logic is:

```text
Read audio sample
        ↓
Store sample in buffer
        ↓
Every hopSize samples:
    compute buffer energy
        ↓
If energy > threshold and refractory period has passed:
    detect onset
    activate digital output pin
    optionally generate audio pulse
    optionally record audio and marker trace
```

## Parameters

The current detector uses the following main parameters:

| Parameter | Description |
| --- | --- |
| `bufferSize` | Number of samples stored in the buffer for energy calculation |
| `hopSize` | Number of samples between consecutive energy calculations |
| `energyThreshold` | Threshold used for detecting an onset |
| `refractoryPeriod` | Minimum time between two detected events |
| `activationDuration` | Duration for which the digital output pin is activated |
| `inputGain` | Input gain for the microphones |
| `recordAudio` | Enables or disables audio and marker recording |
| `recordDuration` | Duration of the recording in seconds |

Some parameters can be set through a `config.txt` file.

Example:

```text
energyThreshold 0.001
recordAudio 1
recordDuration 20
inputGain 55
```

If the configuration file cannot be read, the script uses the default values defined in the source code.

## Outputs

The script can produce three types of output.

### 1. Digital trigger

When an onset is detected, a digital output pin is set to `HIGH` for a short period. This can be used as an event marker for synchronization with EEG or other recording systems.

### 2. Audio pulse

During trigger activation, the script can write a short sine tone to the audio output. This is mainly useful for testing and debugging the timing of detected events.

### 3. Optional recording

If recording is enabled, the script stores the audio signal and the marker trace. At the end of the recording, the audio is saved as a `.wav` file and the marker trace is saved as a `.txt` file.

## Current status

The current implementation is an **audio event detector**, not yet an **audio event classifier**.

It detects whether an acoustic event has occurred, but it does not yet assign semantic labels to events. For example, it does not distinguish between speech, impact sounds, mechanical noise, movement artefacts, or other environmental sounds.

The current detector is useful as a first prototype because it establishes the basic real-time pipeline:

```text
microphone input → detection → trigger output → optional recording
```

## Limitations

The current implementation has several limitations:

* Detection is based only on broadband signal energy.
* The threshold is fixed and may need manual tuning for each environment.
* The detector currently uses one audio channel for event detection, although stereo input is available.
* The detector does not classify event types.
* Loud background noise may cause false detections.
* Quiet but relevant events may be missed.
* Slow changes in overall loudness may affect detection reliability.
* No spectral, temporal, or spatial features are currently used.
* The detector has not yet been systematically evaluated against manually annotated events.

## Possible future improvements

Several extensions could improve the robustness and usefulness of the system.

### Adaptive thresholding
### Stereo-based detection
### Spectral features
### Event classification
### Offline evaluation

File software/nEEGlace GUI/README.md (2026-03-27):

# nEEGlace GUI
The GUI is developed and maintained separately [here](https://github.com/T-PsyOl/nEEGlace-GUI). Make sure to always use the latest version from this repository.
The GUI application for nEEGlace device is built with CustomTkinter, PyQt5 and LSL.  

The GUI helps to:
1. Configure the EEG Device
2. Configure the audio detection parameters for BELA
3. Real-time visualisation of the EEG signal, Sound trigger and Real-time ERP plotting 

## Installation Guide

```bash
git clone https://github.com/T-PsyOl/nEEGlace-GUI.git
cd nEEGlace-GUI
pip install -r requirements.txt
```

## Run GUI

```bash
python run.py
```

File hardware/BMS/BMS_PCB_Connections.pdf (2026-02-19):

## BMS PCB- Connections

### 1. Components:

- The HiLetgo board is the 5V source.
- The Bela runs directly on 5V.
- The OpenBCI needs 3.3V.
- The LDO regulator (MCP1700) converts 5V to 3.3V.
2. Preparing the PCB

If the PCB does not have holes drilled, then:

Tools we Need:

- A small PCB hand drill or Dremel
- 0.8 mm or 1.0 mm drill bit
- Eye protection (PCB dust is sharp and irritating)

How to Drill Properly:

1. Locate the gold circular pads. These are your drill targets.
2. Place the drill bit exactly in the center of the pad.
3. Drill straight down with light pressure.
4. After drilling, scrape away rough copper edges so the surface is clean and flat.

Note: Crooked holes make soldering harder.

3. Soldering the Components
A. LDO Regulator (MCP1700)

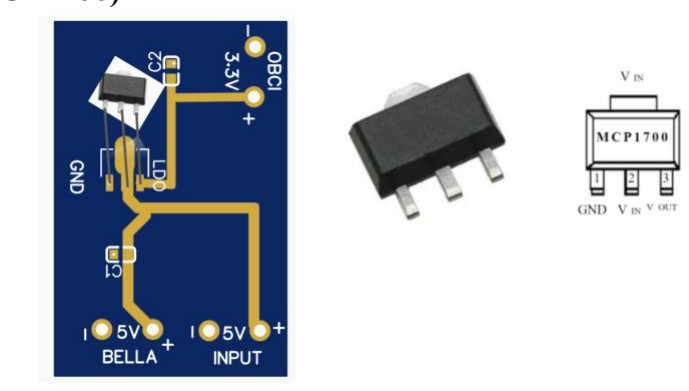
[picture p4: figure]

1. Check orientation carefully. The flat side of the MCP1700 must match the board marking as shown in the above figure.
2. Insert the three legs through the holes so the body sits close to the PCB.
3. Flip the board and solder each leg:
a. Heat the pad and the leg at the same time.
b. Add a small amount of solder.
c. You want a clean cone shape, not a blob.
4. Trim the extra leg length after soldering.

Note: Avoid solder touching adjacent pins.

B. Capacitors (C1 and C2)

These stabilize the voltage and reduce electrical noise.

- Solder C1 (100uF) near the INPUT side.
- Solder C2 (10uF) near the OBCI side.
Make sure they sit flat against the board and are properly soldered.
If these are missing or poorly soldered, you may get unstable sensor readings later.

4.Final Wiring Map

Follow this exactly. Power wiring mistakes are expensive.

Main Power In: PCB INPUT (+) and (−) → HiLetgo 5V and GND

Red to positive, Black to ground as shown in the figure below.

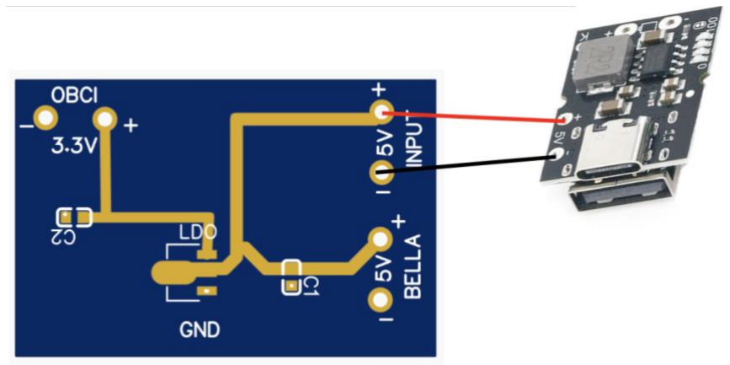
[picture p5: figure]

Bela Power: PCB BELLA (+) and (−) → Bela 5V and GND

Red to positive, Black to ground as shown in the figure below.

Do not guess polarity. Double check every connection before applying power.

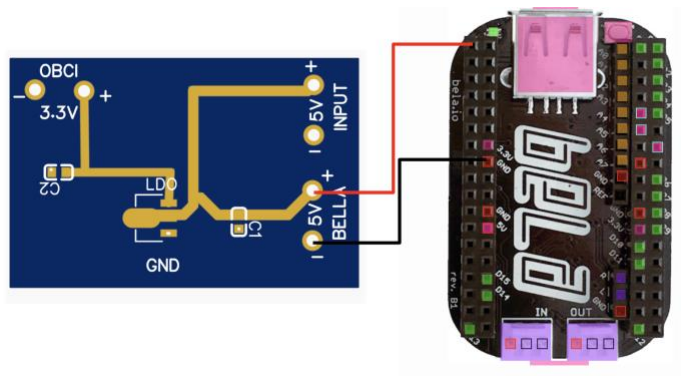
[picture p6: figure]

5. If Something Does Not Work

Nothing turns on:

1. Check the battery and the wiring between battery and HiLetgo board.

2. Bela works but OpenBCI does not: The LDO may be reversed. Confirm the flat side orientation.
3. Boards get hot: Likely a short circuit. Inspect for solder bridges between pads.
4. OpenBCI receives 5V: This is dangerous. The LDO pins may be bridged with solder. Fix immediately.
5. Sensor data looks unstable: Check that C1 and C2 are properly soldered. They smooth the power supply.
6. Final Safety Check Before Connecting Devices
1. Tug Test: Gently pull each wire. If it moves, resolder it.
2. Visual Inspection: Look closely for stray wire strands or solder bridges.
3. Multimeter Check:
With the battery connected:
- INPUT should read around 5V
- BELA port should read around 5V
- OBCI port should read about 3.3V

If you do not see these values, stop and fix the issue before connecting your boards.

4. Pre Power Check

Before connecting Bela or OpenBCI, do these two tests.
I. Continuity Test:
- Set the multimeter to continuity mode.
- Touch one probe to a positive hole and the other to a negative hole.
- It should not beep.
- If it beeps, you have a short circuit. Find it and remove the extra solder before proceeding.

II. Voltage Test

1. Turn the system on.
2. Measure:
- INPUT: around 5V
- BELA: around 5V
- OBCI: about 3.3V

If OpenBCI shows 5V, do not connect it. Fix the regulator issue first.

7. Final Assembly
Once everything measures correctly:
1. Disconnect the battery.
2. Solder final wires to Bela and OpenBCI.
3. Double check polarity again.
4. Reconnect the battery and confirm status LEDs turn on normally. Build slowly. Check twice. Power once.

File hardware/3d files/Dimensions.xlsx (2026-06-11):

Component | L in mm | W in mm | H in mm | Weight in g
Bela Gem Stereo | 58 | 45 | 22
Battery | 97.2 | 31.5 | 19.8 | 108
Bela Cape | 70 | 45 | 10
OBCI | 61.2 | 61.2 | 25 |  | Octogonal inches
BMS PCB | 40 | 25 | 4
HiletGo | 25 | 20 | 10 | ‎22.7
Switch | 14.1 | 7.5 | 8.1 | 1
Connectors | 50 | 10 | 0.8
Samtec Connector PCB | 27 | 21 | 7 |  | Height Inclusive of Samtec connector
Samtec Connector | 27 | 6 | 5

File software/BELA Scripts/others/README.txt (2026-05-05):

README

Audio Onset Detection using Energy and Spectral Features
This project uses the Bela platform to detect audio onsets using energy and spectral features. The code is optimized for performance and logs onset events to a CSV file every second.
Features

    Audio onset detection using energy and spectral features
    Logging of onset events to a CSV file every second
    Configurable parameters for energy threshold, recording duration, and input gain
    Support for audio recording and saving to a WAV file
    Digital output pin activation after onset detection

Requirements

    Bela platform
    C++ compiler
    FFTW library for FFT calculations
    AudioFile library for audio recording and saving

Configuration
The project uses a configuration file config.txt to set the following parameters:

    energyThreshold: the threshold for detecting an onset
    recordAudio: whether to record audio or not (0 or 1)
    recordDuration: the duration of audio recording in seconds
    inputGain: the input gain for the microphones

Usage

    Compile the code using the Bela platform's compiler.
    Run the code on the Bela platform.
    The code will start detecting audio onsets and logging them to a CSV file every second.
    If audio recording is enabled, the code will save the recorded audio to a WAV file.

CSV File Format
The CSV file will contain the following columns:

    timestamp: the timestamp of the onset event in seconds
    detection: a flag indicating whether an onset was detected (1) or not (0)
    rms: the root mean square value of the audio signal
    freqContent: the frequency content of the audio signal

Notes

    The code uses a ring buffer to store onset events, which are logged to the CSV file every second.
    The code uses a digital output pin to activate after onset detection.
    The code supports audio recording and saving to a WAV file.

Troubleshooting

    If the code is not detecting onsets, check the energy threshold value and adjust it accordingly.
    If the code is not logging onset events to the CSV file, check the CSV file path and ensure that the file is not open in another program.
    If the code is not recording audio, check the audio recording settings and ensure that the audio input is working correctly.
    If the Compiler cant find "fftw3" add the following command to the “Make Parameters” section in the IDE's Settings: “LDLIBS=-lfftw3f”.
    This creates a link to the library, which should then allow the program to run. 
    If you want to go directly to the bela board to create a Makefile for the project, follow these steps:
    1.    Log in to bela as root
    	a.    Enter the following in a command prompt:
        	i.    ssh root@bela
       		ii.   Sometimes you may need to enter the IP address instead of “bela”. In that case, you might get an error saying you can’t access it. To fix this, go to 		      the following path: “C:\Users\‘yourName‘\.ssh”. ‘yourName’ should be your actual name. There, you’ll find a file named:                 “known_hosts”. 		      Find the line that starts with “bela.local” and delete only that line. Then log in again with ssh root@bela and press “yes” when prompted
        	iii.  The cmd line should now display the following: “root@bela:~#”
    2.    Next, navigate to your project
    	a.    Type `cd /root/Bela/“MyProject”`, where “MyProject” is the name of the project you're looking for
    	b.    You should now see `root@bela:~/Bela/projects/MyProject#`
    3.    Now open the Makefile
    	a.    To do this, enter “nano Makefile”
   	b.    You will now see either an empty or an existing Makefile. (In most cases, if nothing has been created in the project yet, it should be empty)

Important Note

    	Because of unoptimized memory usage for saving the .wav file we cant have a recording Duration higher than 300. We are working on it.

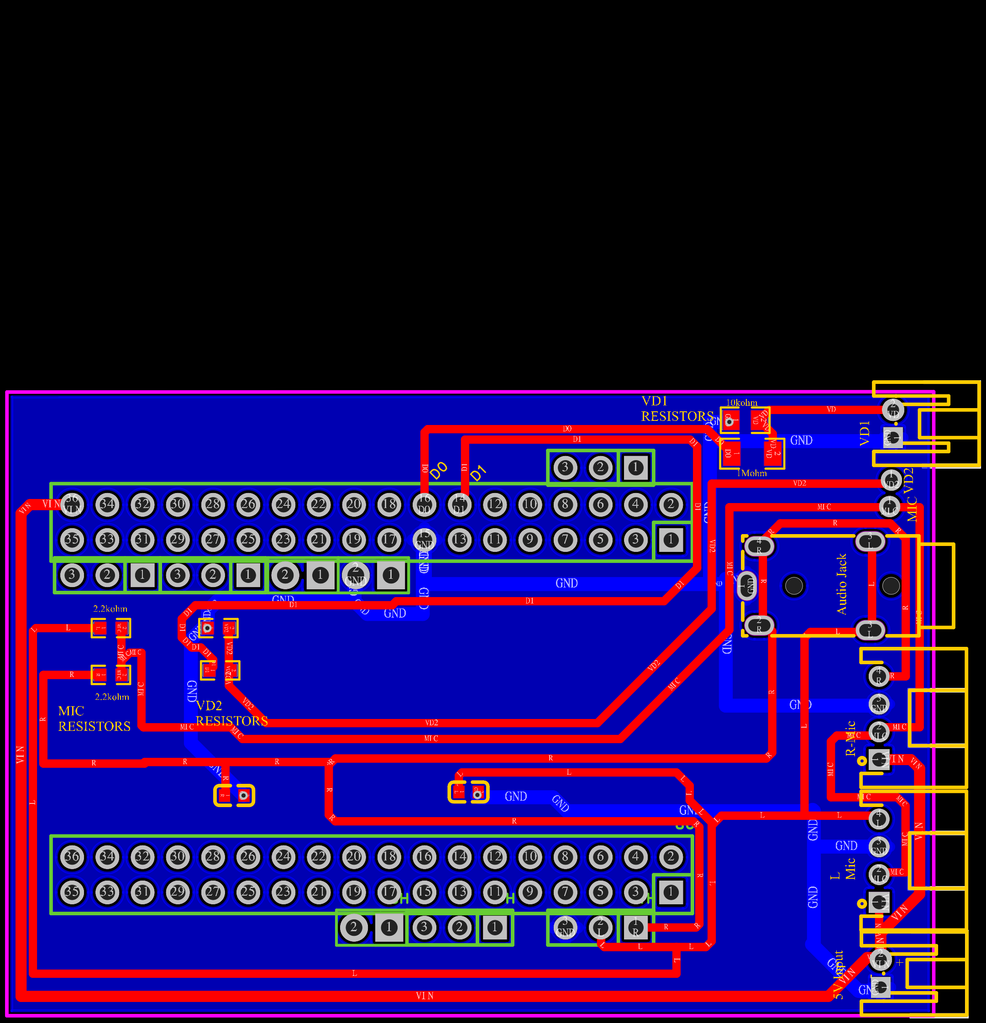
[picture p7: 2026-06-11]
hardware/Bela Cape/PCB_BelaCape.png

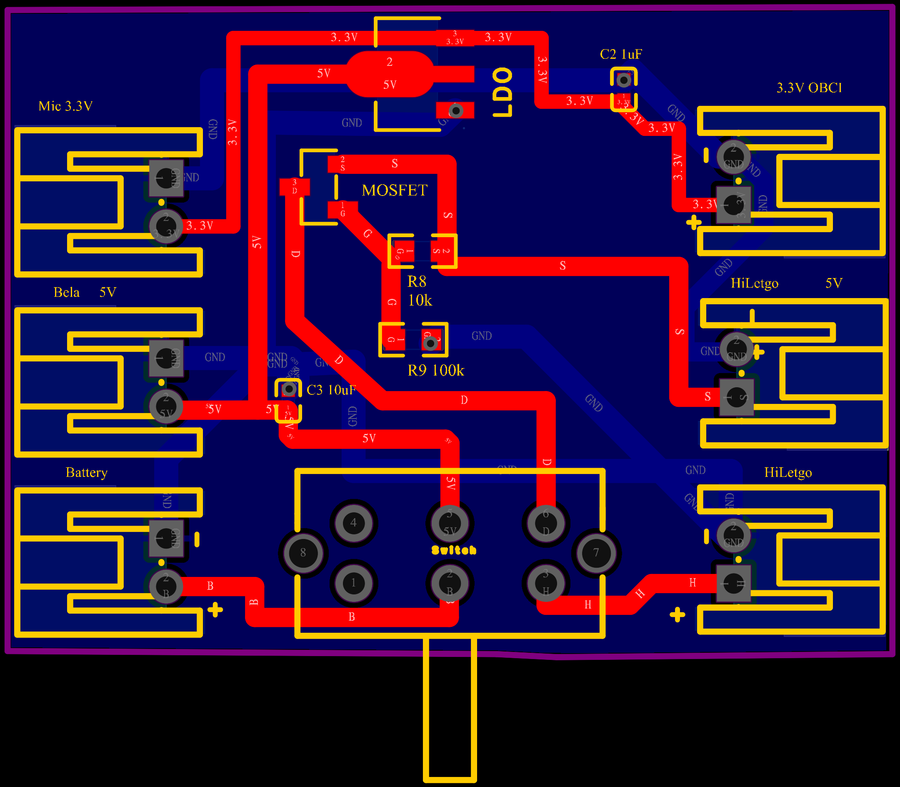
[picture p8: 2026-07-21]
hardware/BMS/PCB_nEEGlace_BMS.png

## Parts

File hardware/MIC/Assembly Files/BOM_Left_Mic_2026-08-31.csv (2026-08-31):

No. | Quantity | Comment | Designator | Footprint | Value | Manufacturer Part | Manufacturer | Supplier Part | Supplier | Add into BOM | Unique ID | Name | Device | 3D Model Title | Convert to PCB | Category | Primary Category | Pin Count | LCSC Stock | LCSC Price | JLCPCB Stock | JLCPCB Price | Layer | Mounting Style | 3D Model Transform | Circluar Pins/Square Pins | Color | Connector Type | Contact Material | Current Rating | Datasheet | Tolerance | Type
1 | 3 | 10nF | C1,C2,C3 | C0402 | 10nF | FCC0402B103K500AT | FOJAN(富捷) | C5137480 | LCSC | yes |  | 10nF | FCC0402B103K500AT | C0402_L1.0-W0.5-H0.5 |  | Capacitors:Multilayer Ceramic Capacitors MLCC - SMD/SMT | Capacitors | 2 |  |  | 9678015 | 0.0007 | T | SMT | 39.37,19.685,0,0,0,0,0,0,0 |  |  |  |  |  | https://item.szlcsc.com/datasheet/FCC0402B103K500AT/5746982.html | ±10%
2 | 2 | 100nF | C4,C5 | C0402 | 100nF | CL05B104KB54PNC | SAMSUNG(三星) | C307331 | LCSC | yes |  | 100nF | CL05B104KB54PNC | C0402_L1.0-W0.5-H0.5 |  | Capacitors:Multilayer Ceramic Capacitors MLCC - SMD/SMT | Capacitors | 2 |  |  | 23004347 | 0.0014 | T | SMT | 39.37,19.685,0,0,0,0,0,0,0 |  |  |  |  |  | https://item.szlcsc.com/datasheet/CL05B104KB54PNC/291005.html | ±10%
3 | 6 | 100kΩ | R1,R2,R3,R4,R5,R6 | R0603 | 100kΩ | FRC0603J104 TS | FOJAN(富捷) | C2907088 | LCSC | yes |  | 100kΩ | FRC0603J104 TS | R0603 |  | Resistors:Chip Resistor - Surface Mount | Resistors | 2 |  |  | 6097472 | 0.0003 | T | SMT | 31.8897,63.7794,0,90,0,0,0,0,0 |  |  |  |  |  |  | ±5% | Thick Film Resistor
4 | 1 | S4B-PH-K-S(LF)(SN) | U1 | CONN-TH_4P-P2.00_S4B-PH-K-S-LF-SN |  | S4B-PH-K-S(LF)(SN) | JST | C157926 | LCSC | yes |  | S4B-PH-K-S(LF)(SN) | S4B-PH-K-S(LF)(SN) | CONN-TH_4P-P2.00_S4B-PH-K-S-LF-SN |  | Connectors:Wire To Board Connector | Connectors | 4 |  |  | 8291 | 0.0102 | T | DIP | 389.80237,299.212,0,0,0,0,0,-96.457,-137.795 |  | White |  | Brass | 2A | https://item.szlcsc.com/datasheet/S4B-PH-K-S(LF)(SN)/169274.html
5 | 1 | LM358ST | U2 | MSOP-8_L3.0-W3.0-P0.65-LS5.0-BL |  | LM358ST | ST(意法半导体) | C54867 | LCSC | yes | gge1 | LM358ST | LM358ST | MSOP-8_L3.0-W3.0-P0.65-LS5.0-BL |  | Amplifiers/Comparators:Operational Amplifier | Amplifiers/Comparators | 8 |  |  | 23991 | 0.0287 | T | SMT | 118.11,196.85,0,0,0,0,0,0,0 |  |  |  |  |  | https://item.szlcsc.com/datasheet/LM358ST/55891.html
6 | 1 | ICS-40638 | U3 | MIC-SMD_L3.5-W2.7_MNR8065S332MT |  | ICS-40638 | TDK InvenSense(应美盛) | C3171798 | LCSC | yes |  | ICS-40638 | ICS-40638 |  |  | Audio Products / Vibration Motors:MEMS Microphones | Audio Products / Vibration Motors | 8 |  |  | 22 | 0.4806 | T | SMT |  |  |  |  |  |  | https://item.szlcsc.com/datasheet/ICS-40638/3733735.html

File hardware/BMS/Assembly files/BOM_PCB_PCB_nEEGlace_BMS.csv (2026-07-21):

No. | Quantity | Comment | Designator | Footprint | Value | Manufacturer Part | Manufacturer | Supplier Part | Supplier | Add into BOM | Unique ID | Name | Device | 3D Model Title | Convert to PCB | Category | Primary Category | Pin Count | LCSC Stock | LCSC Price | JLCPCB Stock | JLCPCB Price | Layer | Mounting Style | 3D Model Transform | Circluar Pins/Square Pins | Color | Connector Type | Contact Material | Current Rating | Datasheet | Tolerance | Type
1 | 2 | 10nF | C2,C3 | C0402 | 10nF | FCC0402B103K500AT | FOJAN(富捷) | C5137480 | LCSC | yes |  | 10nF | FCC0402B103K500AT | C0402_L1.0-W0.5-H0.5 |  | Capacitors:Multilayer Ceramic Capacitors MLCC - SMD/SMT | Capacitors | 2 |  |  | 10052136 | 0.0009 | T | SMT | 39.37,19.685,0,0,0,0,0,0,0 |  |  |  |  |  | https://item.szlcsc.com/datasheet/FCC0402B103K500AT/5746982.html | ±10%
2 | 1 | LDO | LDO | SOT-89-3_L4.5-W2.5-P1.50-LS4.2-BR |  | MCP1700T-3302E/MB | MICROCHIP(美国微芯) | C632000 | LCSC | yes | ggef92d15956a5a7db1 | LDO | LDO | SOT-89-3_L4.3-W2.5-H1.6-LS4.1-P1.50 |  |  |  | 3 |  |  | 4511 | 0.0956 | T | SMT | 161.417,169.291,0,180,0,0,-11.809,-0.002,0
3 | 1 | SI2301CDS-T1-GE3-ES | MOSFET | SOT-23-3_L2.9-W1.3-P1.90-LS2.4-BR |  | SI2301CDS-T1-GE3-ES | ElecSuper(静芯) | C5224168 | LCSC | yes | ggeb47bb978aded6c68 | SI2301CDS-T1-GE3-ES | SI2301CDS-T1-GE3-ES | SOT-23-3P_L2.9-W1.3-H1.0-LS2.4-P0.95 |  |  |  | 3 |  |  | 113649 | 0.0028 | T | SMT | 98.425,114.173,0,180,0,0,0,-0.001,0
4 | 2 | 100kΩ | R1,R2 | R0603 | 100kΩ | FRC0603J104 TS | FOJAN(富捷) | C2907088 | LCSC | yes |  | 100kΩ | FRC0603J104 TS | R0603 |  | Resistors:Chip Resistor - Surface Mount | Resistors | 2 |  |  | 6909044 | 0.0004 | T | SMT | 31.8897,63.7794,0,90,0,0,0,0,0 |  |  |  |  |  |  | ±5% | Thick Film Resistor
5 | 1 | SW-TH_EG2210 | U1 | SW-TH_EG2210 |  | EG2210 | E-Switch | C3664585 | LCSC | yes | gge22846 | SW-TH_EG2210 | SW-TH_EG2210 | SW-TH_EG2210 |  |  |  | 8 |  |  | 0 | 0.0846 | T | DIP | 496.456,503.936,0,0,0,0,0,-118.228,-118.11
6 | 6 | CONN-TH_S2B-PH-K-S-LF-SN | U2,U3,U4,U5,U6,U7 | CONN-TH_S2B-PH-K-S-LF-SN |  | S2B-PH-K-S(LF)(SN) | JST | C173752 | LCSC | yes | gge23270,gge23372,gge23474,gge23576,gge23678,gge23780 | CONN-TH_S2B-PH-K-S-LF-SN | CONN-TH_S2B-PH-K-S-LF-SN | CONN-TH_HR-PH2.0-WI-2P |  |  |  | 2 |  |  | 79846 | 0.0059 | T | DIP | 236.22,303.149,0,180,0,0,0,95.471,-137.795

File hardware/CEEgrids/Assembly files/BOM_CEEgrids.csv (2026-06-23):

ID | Name | Designator | Footprint | Quantity | Manufacturer Part | Manufacturer | Supplier | Supplier Part | Price
1 | SMD1,27-2,54 | PAD9,PAD10,PAD11,PAD12,PAD13,PAD14,PAD15,PAD16,PAD17,PAD18 | SMD1,27-2,54 | 10

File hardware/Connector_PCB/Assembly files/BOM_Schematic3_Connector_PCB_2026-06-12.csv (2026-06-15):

No. | Quantity | Comment | Designator | Footprint | Value | Manufacturer Part | Manufacturer | Supplier Part | Supplier | Add into BOM | Unique ID | Name | Device | 3D Model Title | Convert to PCB | Category | Primary Category | Pin Count | LCSC Stock | LCSC Price | JLCPCB Stock | JLCPCB Price | Layer | Mounting Style | 3D Model Transform | Circluar Pins/Square Pins | Color | Connector Type | Contact Material | Current Rating | Datasheet | Tolerance | Type
1 | 5 | HX PH254-01-02-Z-L11.5 male header connector | H1,H2,H3,H4,H5 | HDR-TH_2P-P2.54-V-M |  | HX PH254-01-02-Z-L11.5 male header connector | hanxia(韩下) | C52016390 | LCSC | yes |  | HX PH254-01-02-Z-L11.5 male header connector | HX PH254-01-02-Z-L11.5 male header connector | HDR2.54-M-LI-1X2P |  | Connectors:Pin Headers | Connectors | 2 |  |  | 16772 | 0.0021 | T | DIP | 200,100,0,0,0,0,0,0,-118.11 | Pin Header |  |  | Brass | 3A | https://item.szlcsc.com/datasheet/HX%2520PH254-01-02-Z-L11.5%2520male%2520header%2520connector/54760435.html

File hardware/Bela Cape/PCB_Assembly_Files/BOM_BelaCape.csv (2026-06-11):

No. | Quantity | Comment | Designator | Footprint | Value | Manufacturer Part | Manufacturer | Supplier Part | Supplier | Add into BOM | Unique ID | Name | Device | 3D Model Title | Convert to PCB | Category | Primary Category | Pin Count | LCSC Stock | LCSC Price | JLCPCB Stock | JLCPCB Price | Layer | Mounting Style | 3D Model Transform | Circluar Pins/Square Pins | Color | Connector Type | Contact Material | Current Rating | Datasheet | Tolerance | Type
1 | 2 | 10uF | C1,C2 | C0603 | 10uF | CL10A106KP8NNNC | SAMSUNG(三星) | C19702 | LCSC | yes |  | 10uF | CL10A106KP8NNNC | C0603_L1.6-W0.8-H0.8 |  | Capacitors:Multilayer Ceramic Capacitors MLCC - SMD/SMT | Capacitors | 2 |  |  | 4410969 | 0.0026 | T | SMT | 62.992,31.496,0,0,0,0,0,0,0 |  |  |  |  |  | https://item.szlcsc.com/datasheet/CL10A106KP8NNNC/20411.html | ±10%
2 | 1 | PJ-322环保 | CN2 | AUDIO-TH_HOOYA_PJ-322 |  | PJ-322环保 | HOOYA(皓宇电子) | C2939185 | LCSC | yes |  | PJ-322环保 | PJ-322环保 | AUDIO-TH_HOOYA_PJ-322 |  | Connectors:Audio Connectors | Connectors | 5 |  |  | 197 | 0.0317 | T | DIP | 291.338,591.53425,0,90,0,0,-116.145,0,-118.11 |  |  | 3.5mm Headphone Jack | Phosphor bronze；Brass | - | https://item.szlcsc.com/datasheet/PJ-322%25E7%258E%25AF%25E4%25BF%259D/3300132.html
3 | 5 | 1x3单排直针2.54mm间距 | H1,H2,H4,H5,H6 | HDR-TH_3P-P2.54-V-M |  | 1x3单排直针2.54mm间距 |  | C9900017402 | LCSC | yes |  | 1x3单排直针2.54mm间距 | 1x3单排直针2.54mm间距 | HDR-TH_3P-P2.54-M-LI-1X3P |  |  |  | 3 |  |  | 0 | 0.0059 | B | DIP | 300.03877,100,0,0,0,0,0,0,-118.11
4 | 3 | HX PH254-01-02-Z-L11.5 male header connector | H3,H7,H8 | HDR-TH_2P-P2.54-V-M |  | HX PH254-01-02-Z-L11.5 male header connector | hanxia(韩下) | C52016390 | LCSC | yes |  | HX PH254-01-02-Z-L11.5 male header connector | HX PH254-01-02-Z-L11.5 male header connector | HDR2.54-M-LI-1X2P |  | Connectors:Pin Headers | Connectors | 2 |  |  | 17308 | 0.0021 | B | DIP | 200,100,0,0,0,0,0,0,-118.11 | Pin Header |  |  | Brass | 3A | https://item.szlcsc.com/datasheet/HX%2520PH254-01-02-Z-L11.5%2520male%2520header%2520connector/54760435.html
5 | 4 | 2.2kΩ | R5,R7,R8,R9 | R0603 | 2.2kΩ | FRC0603F2201TS | FOJAN(富捷) | C2907005 | LCSC | yes |  | 2.2kΩ | FRC0603F2201TS | R0603 |  | Resistors:Chip Resistor - Surface Mount | Resistors | 2 |  |  | 1746504 | 0.0003 | T | SMT | 31.8897,63.7794,0,90,0,0,0,0,0 |  |  |  |  |  |  | ±1% | Thick Film Resistor
6 | 1 | 1MΩ | R6 | R1206 | 1MΩ | 1206W4F1004T5E | UNI-ROYAL(厚声) | C17927 | LCSC | yes |  | 1MΩ | 1206W4F1004T5E | R1206_L3.2-W1.6-H0.6 |  | Resistors:Chip Resistor - Surface Mount | Resistors | 2 |  |  | 3780570 | 0.0007 | T | SMT | 125.984,62.992,0,0,0,0,0,0,0 |  |  |  |  |  | https://item.szlcsc.com/datasheet/1206W4F1004T5E/18615.html | ±1% | Thick Film Resistor
7 | 1 | 10kΩ | R10 | R0805 | 10kΩ | FRC0805J103TS | FOJAN(富捷) | C2930231 | LCSC | yes |  | 10kΩ | FRC0805J103TS | R0805_L2.0-W1.3-H0.6 |  | Resistors:Chip Resistor - Surface Mount | Resistors | 2 |  |  | 5976683 | 0.0003 | T | SMT | 78.74,51.181,0,0,0,0,0,-0.0005,0 |  |  |  |  |  |  | ±5% | Thick Film Resistor
8 | 1 | PocketBeagle3D_for_Belamini | REF** | Bela:PocketBeagle3D_for_Belamini |  |  |  |  |  | yes | 36725bbfc0c5b046 | PocketBeagle3D_for_Belamini | Bela:PocketBeagle3D_for_Belamini |  |  |  |  | 0 |  | 1.2657 |  |  | T | SMT
9 | 2 | S2B-PH-K-S(LF)(SN) | U1,U4 | CONN-TH_S2B-PH-K-S-LF-SN |  | S2B-PH-K-S(LF)(SN) | JST | C173752 | LCSC | yes |  | S2B-PH-K-S(LF)(SN) | S2B-PH-K-S(LF)(SN) | CONN-TH_HR-PH2.0-WI-2P |  | Connectors:Wire To Board Connector | Connectors | 2 |  |  | 137049 | 0.0059 | T | DIP | 236.22,303.149,0,180,0,0,0,95.472,-137.795 |  | White |  | Brass | 2A | https://item.szlcsc.com/datasheet/S2B-PH-K-S(LF)(SN)/185142.html
10 | 2 | S4B-PH-K-S(LF)(SN) | U5,U6 | CONN-TH_4P-P2.00_S4B-PH-K-S-LF-SN |  | S4B-PH-K-S(LF)(SN) | JST | C157926 | LCSC | yes |  | S4B-PH-K-S(LF)(SN) | S4B-PH-K-S(LF)(SN) | CONN-TH_4P-P2.00_S4B-PH-K-S-LF-SN |  | Connectors:Wire To Board Connector | Connectors | 4 |  |  | 63006 | 0.0102 | T | DIP | 389.80237,299.212,0,0,0,0,0,-96.457,-137.795 |  | White |  | Brass | 2A | https://item.szlcsc.com/datasheet/S4B-PH-K-S(LF)(SN)/169274.html
11 | 2 | HMNDSH25-1801A121TBB | U7,U8 | HDR-TH_36P-P2.54-V-F-R2-C18-S2.54-2 |  | HMNDSH25-1801A121TBB |  | C9900108629 | LCSC | yes |  | HMNDSH25-1801A121TBB | HMNDSH25-1801A121TBB | HDR-TH_36P-P2.54-V-F-R2-C18-S2.54-2 |  |  |  | 36 |  |  | 0 | 0.0059 | B | DIP | 1799.99648,196.85,0,0,0,0,0,0,-118.11

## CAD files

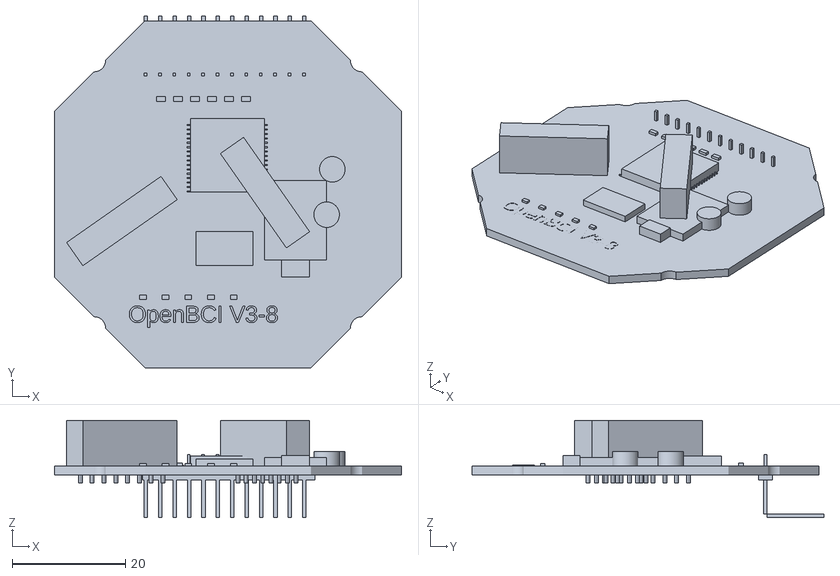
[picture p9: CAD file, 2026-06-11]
hardware/3d files/OpenBCI.stl
61.2 x 62.0 x 17.1

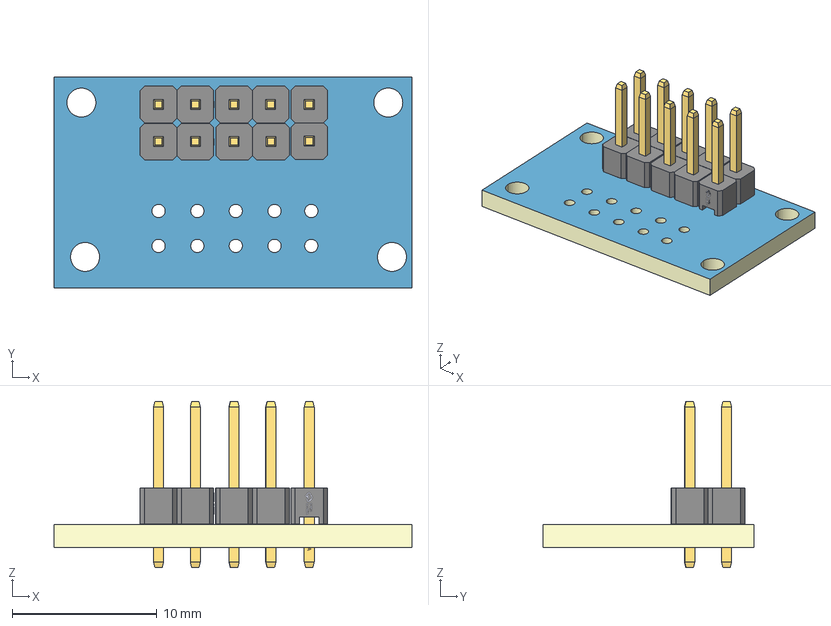
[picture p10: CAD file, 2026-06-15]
hardware/3D_Connector_PCB_.step
24.7 x 14.6 x 11.5 mm
Board~izJk
TopCopper~izJk
BottomCopper~izJk
TopSilkscreen~izJk
BottomSilkscreen~izJk
TopFpcStiffener~izJk
BottomFpcStiffener~izJk
HDR-TH_2P-P2.54-V-M~HDR2.54-M-LI-1X2P~rAs8 x 5

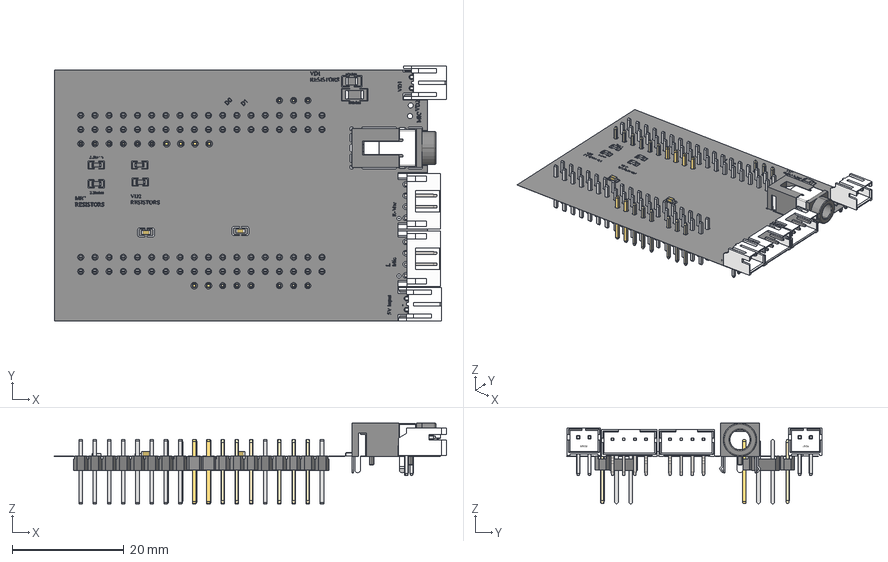
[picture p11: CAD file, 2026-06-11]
hardware/Bela Cape/3D_BelaCape.step
70.2 x 45.7 x 14.5 mm
Board~vyOB
TopCopper~vyOB
BottomCopper~vyOB
TopSilkscreen~vyOB x 145
BottomSilkscreen~vyOB x 11
TopFpcStiffener~vyOB
BottomFpcStiffener~vyOB
AUDIO-TH_HOOYA_PJ-322~AUDIO-TH_HOOYA_PJ-322~vyOB
CONN-TH_4P-P2.00_S4B-PH-K-S-LF-SN~CONN-TH_4P-P2.00_ S4B-PH-K-S-LF-SN~vyOB x 2
CONN-TH_S2B-PH-K-S-LF-SN~CONN-TH_HR-PH2.0-WI-2P~vyOB x 2
R0603~R0603~vyOB x 4
C0603~C0603_L1.6-W0.8-H0.8~vyOB x 2
R1206~R1206_L3.2-W1.6-H0.6~vyOB
R0805~R0805_L2.0-W1.3-H0.6~vyOB
HDR-TH_2P-P2.54-V-M~HDR2.54-M-LI-1X2P~vyOB x 3
HDR-TH_3P-P2.54-V-M~HDR-TH_3P-P2.54-M-LI-1X3P~vyOB x 5
HDR-TH_36P-P2.54-V-F-R2-C18-S2.54-2~HDR-TH_ 36P-P2.54-V-F-R2-C18-S2.54-2~vyOB x 2

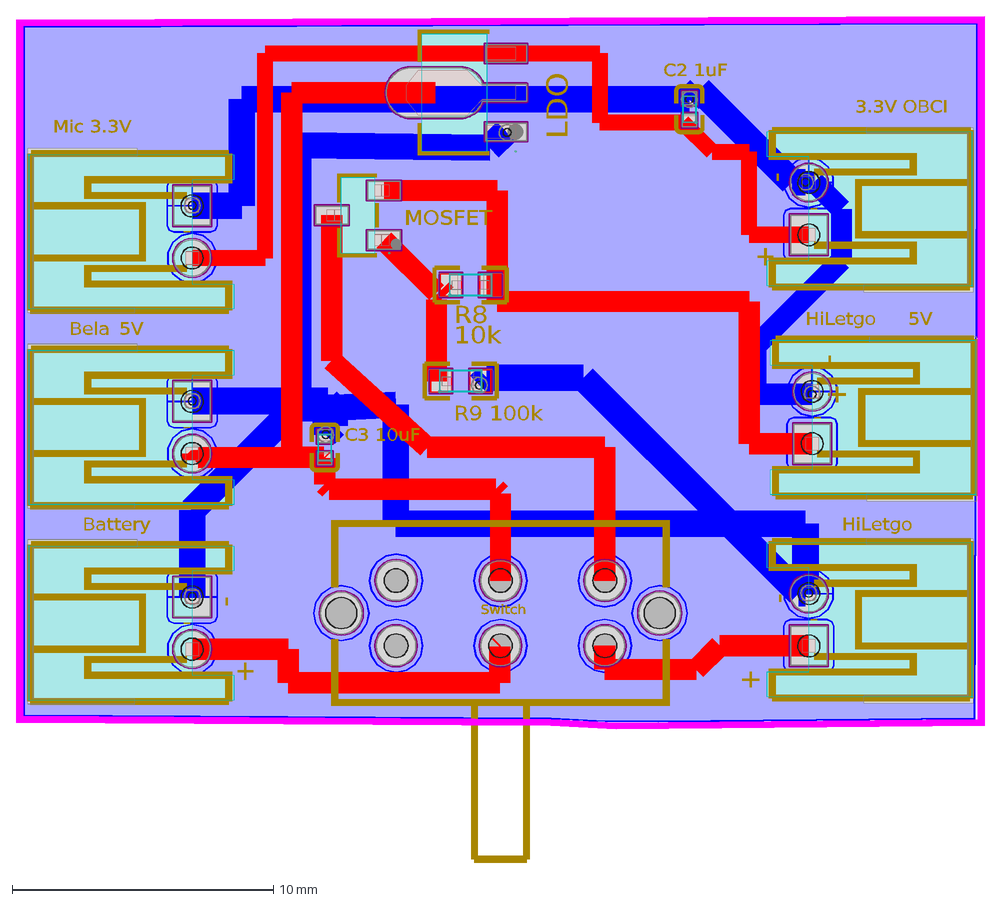
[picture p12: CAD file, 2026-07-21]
hardware/BMS/PCB_nEEGlace_BMS.dxf
+
5V
-
Switch
HiLetgo
Mic 3.3V
Battery
Bela
3.3V OBCI
R8
10k
R9 100k
C3 10uF
C2 1uF
LDO
MOSFET

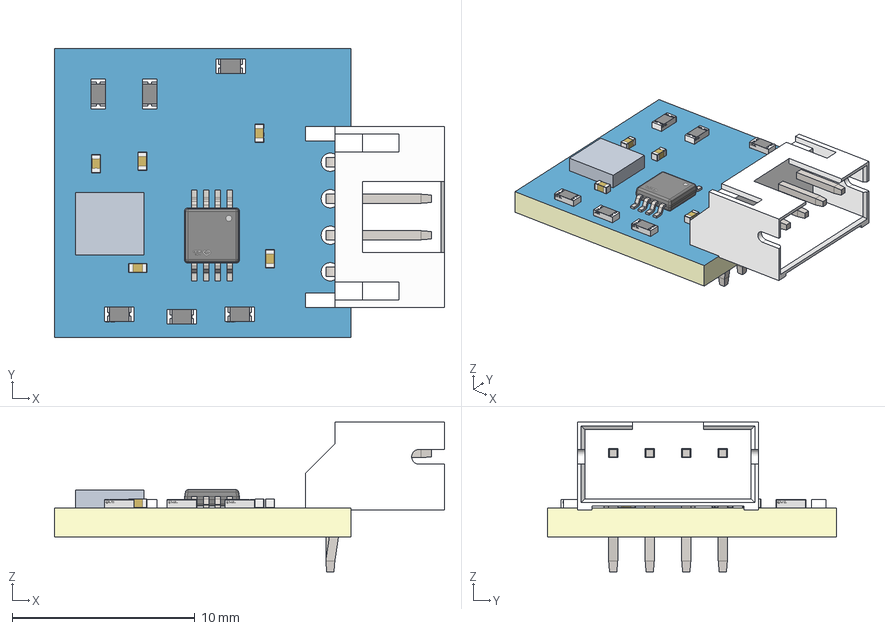
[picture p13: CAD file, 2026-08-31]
hardware/MIC/3D_Mic.step
21.4 x 15.8 x 8.20 mm
Board~14yo
TopCopper~14yo
BottomCopper~14yo
TopSilkscreen~14yo
BottomSilkscreen~14yo
TopFpcStiffener~14yo
BottomFpcStiffener~14yo
MIC-SMD_L3.5-W2.7_MNR8065S332MT~default_model~14yo
C0402~C0402_L1.0-W0.5-H0.5~RYL1 x 5
CONN-TH_4P-P2.00_S4B-PH-K-S-LF-SN~CONN-TH_4P-P2.00_S4B-PH-K-S-LF-SN~xwKF
MSOP-8_L3.0-W3.0-P0.65-LS5.0-BL~MSOP-8_L3.0-W3.0-P0.65-LS5.0-BL~B59A
R0603~R0603~Q5CU x 6

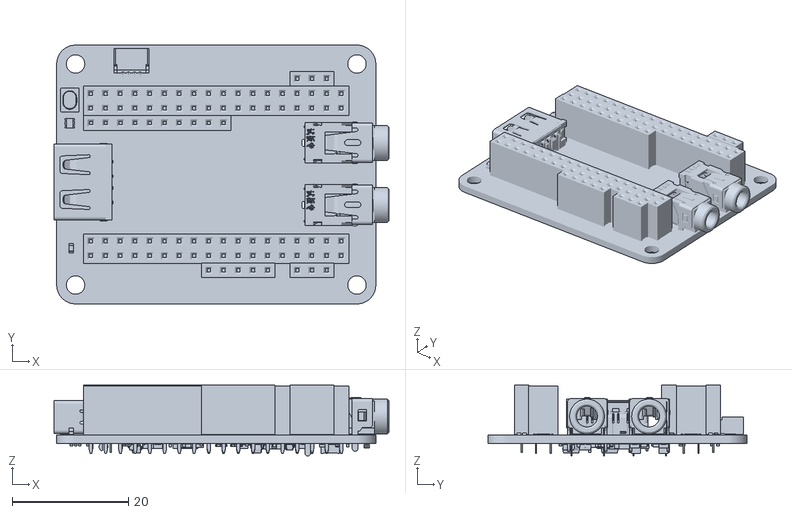
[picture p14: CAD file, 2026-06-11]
hardware/3d files/Bela_3D.stl
57.7 x 44.6 x 12.2

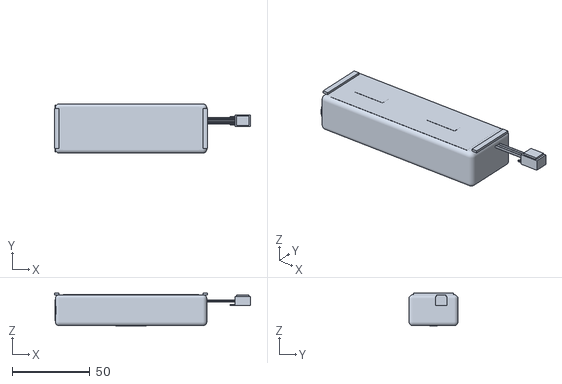
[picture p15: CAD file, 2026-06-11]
hardware/3d files/Battery_3D.stl
125.7 x 31.5 x 21.1

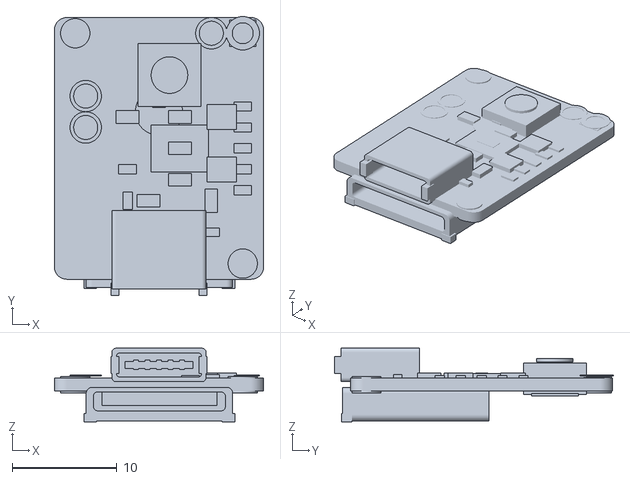
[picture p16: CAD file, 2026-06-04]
hardware/3d files/Hiletgo_3d.stl
20.0 x 26.6 x 7.03

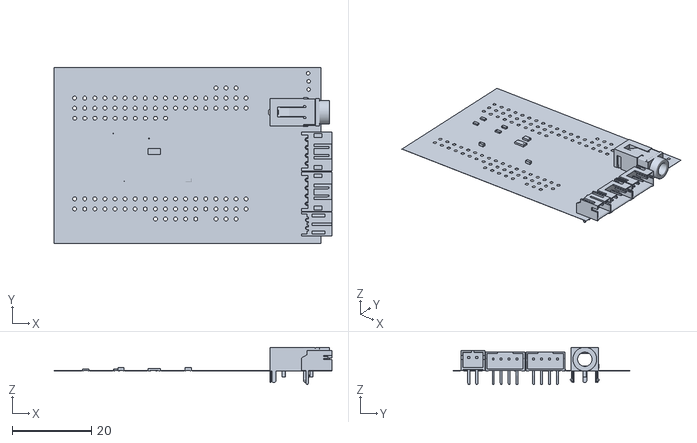
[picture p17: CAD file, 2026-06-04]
hardware/3d files/Bela_Cape.stl
70.0 x 44.4 x 9.40

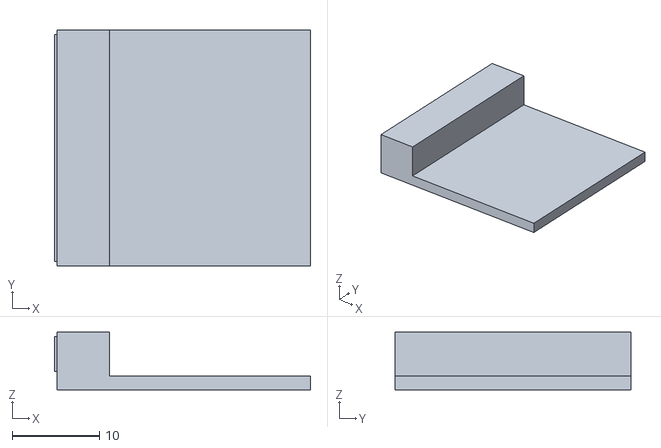
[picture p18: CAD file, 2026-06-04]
hardware/3d files/Samtec_PCB_3d.stl
29.3 x 27.0 x 6.60

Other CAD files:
hardware/Connector_PCB/3D_Connector_PCB_.step
hardware/3d files/_nEEGlace_BMS.stl

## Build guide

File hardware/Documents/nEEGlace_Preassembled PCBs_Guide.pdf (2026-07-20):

nEEGlace Assembly Guide |

# nEEGlace

## Assembly Guide for Preassembled PCBs | Step-by-Step Build Manual

Boards in this kit:

!

Note: Before you begin: This guide assumes basic soldering experience. Read every step fully before picking up your iron. A misoriented component can destroy the board.

nEEGlace Build Guide v1.0Page 1

4

PCBs to build

22

unique components

10

wiring steps

BMS PCB
Battery Management

Bela Cape PCB
Audio Processor

Left MIC PCB
Left Microphone

Right MIC PCB
Right Microphone

## SECTION 1 — Tools and Safety

### 1.1 Tools Required

You will need all of the following before starting:

Soldering iron (temp-controlled, 320-350°C) | Fine-tip solder (0.5 mm or thinner, lead-free OK)
Flux pen (no-clean) | Solder wick/desoldering pump
Magnifying glass or USB microscope | Multimeter (voltage + continuity modes)
Isopropyl alcohol (IPA) + cotton swab for cleaning | ESD mat or anti-static wrist strap
Heat gun (200W) | Soldering iron paste
Tweezers | Soldering flux

TIP

TIP: Work on a bright, flat surface. A white sheet of paper under your board makes dropped SMD components much easier to find.

### 1.2 Safety Rules

!

RULE 1: Always switch the BMS power switch to OFF before handling any wiring. Never connect the battery until Step 4.1.

!

RULE 2: SMD components are tiny and static-sensitive. Always wear an anti-static strap or regularly touch a grounded metal object.

!

RULE 3: Double-check component orientation BEFORE soldering. A backwards MOSFET or LDO can permanently damage the board.

nEEGlace Build Guide v1.0Page 2

## SECTION 2 — Component Identification Guide

Every component in this kit has an ID number (e.g. [C1], [R3]). Learn to identify each one before you solder. This section is your visual dictionary.

### 2.1 Resistors

Resistors slow down or limit electrical current. Think of them as narrow pipes in a water system — they control how much electricity flows through.

ID | Part Name | What It Does | How to Identify It
R1 | 10 kΩ Resistor x2 (MIC bias) | Sets the bias voltage for the microphone circuit, ensures the mic gets the right operating conditions | SMD, black rectangle ~1.6mm×0.8mm (0603). Marked '103' on top. Used on Bela Cape PCB.
R2 | 2.2 kΩ Resistor x2 (MIC bias) | Limits current into the mic bias capacitors, prevents voltage spikes | SMD, black rectangle ~1.6mm×0.8mm. Marked '222'. Used on Bela Cape PCB.
R3 | 1 MΩ Resistor (VD1 upper) | The upper arm of the bio-signal voltage divider scales down the OpenBCI signal to safe levels | SMD, marked '105'. Very high resistance keeps the circuit from loading the bio-signal. Bela Cape.
R4 | 10 kΩ Resistor (VD1 lower) | Lower arm of VD1 divider, works with R3 to produce exactly 33mV output | SMD, marked '103'. Goes next to R3 on the Bela Cape PCB.
R5 | 10 kΩ x2 (MIC gain) | Sets the gain/amplification of the op-amp on each MIC PCB | SMD, marked '103'. Two of these per MIC board. Part of the op-amp feedback loop.
R6 | 100 kΩ (MIC bias) | Provides a high-impedance bias reference for the MEMS microphone | SMD, marked '104'. One per MIC board. Slightly larger footprint than 10k.
R7 | VD2 resistors | Second voltage divider pair, conditions signal for another measurement channel | Per schematic values, located near the VD2 label on the Bela Cape PCB.
R8 | 10 kΩ (BMS gate bias) | Pulls the MOSFET gate, controls when charging protection activates | SMD on BMS PCB. Must not be confused with 100kΩ, check the value before placing.
R9 | 100 kΩ (BMS gate bias) | Second gate bias resistor, works with R8 to set MOSFET switching threshold | SMD on BMS PCB. 10x higher value than R8, marking reads '104'.

How to read SMD resistor codes:
SMD resistors use a 3-digit code: first two digits are the value, third is the multiplier (number of zeros to add). 103 = 10 × 10³ = 10,000 Ω = 10 kΩ
104 = 10 × 10⁴ = 100,000 Ω = 100 kΩ
105 = 10 × 10⁵ = 1,000,000 Ω = 1 MΩ
222 = 22 × 10² = 2,200 Ω = 2.2 kΩ

nEEGlace Build Guide v1.0Page 3

### 2.2 Capacitors

Capacitors store and release small bursts of electrical charge. They smooth out voltage wobbles, filter noise, and act as buffers between components.

ID | Part Name | What It Does | How to Identify It
C1 | 10 µF Capacitor x2 (MIC bias caps) | Smooths the MIC bias voltage; without these, the mic would hear its own power supply hum | SMD, slightly taller than resistors. May be tan/beige colored. Bela Cape PCB positions C1, C2.
C2 | 1 µF Capacitor (BMS decoupling) | Decouples the LDO output, filters fast voltage spikes that could destabilize the 3.3V rail | SMD, smaller than 10µF caps. Marked '105' or just a dot. BMS PCB.
C3 | 10 µF Capacitor (BMS decoupling) | Large decoupling cap absorbs slow power fluctuations from the battery | SMD, same footprint as C1/C2 on Bela Cape. BMS PCB.
C4 | 10 µF x2 (MIC board decoupling) | Power supply decoupling on each MIC PCB keeps the op-amp from oscillating | Two per MIC board. Placed near op-amp power pins.
C5 | 10 µF x1 (MIC board bias) | Additional decoupling for the 100kΩ mic bias resistor network | One per MIC board. Silkscreen label confirms placement.

Capacitor polarity warning:
Electrolytic capacitors (cylindrical, through-hole) have a + and − side. The LONGER leg is positive (+). The WHITE STRIPE on the body marks the negative (−) side.
The SMD ceramic capacitors in this kit (tan/beige blocks) are non-polar — you can solder them either way.

### 2.3 Active Components — The Smart Parts

ID | Part Name | What It Does | How to Identify It
U1 | LDO( MCP1700T) | Low-Dropout Regulator. Converts the 5V from the HiLetgo module down to a clean, stable 3.3V for mics and OpenBCI. 'LDO' means it can regulate even when the input is only slightly above the output. | SOT-89-3 package: flat tab on one side, 3 legs on the other. Legs = IN, GND, OUT. Check the datasheet before soldering. On the BMS PCB.
U2 | MOSFET (SSI2301CDS) | The electronic switch disconnects the battery load when USB charging is connected. Protects the battery from being charged and discharged simultaneously. | SOT-23-3P package: tiny, 3 legs. Legs = Gate (G), Source (S), Drain (D). ORIENTATION IS CRITICAL. Dot or marking on package = pin 1 = Gate.

nEEGlace Build Guide v1.0Page 4

U3 | Op-Amp (MIC PCB)(MAX74810) | Operational Amplifier. Amplifies the tiny signal from the MEMS microphone to a usable audio level. Acts like a hearing aid for the circuit. | SMD IC, 8-pin SOIC or TSSOP package. Pin 1 is marked with a dot or notch. Two on each MIC PCB.
MIC | MEMS Mic(ICS-40638) | Analog MEMS (Micro-Electro-Mechanical System) microphone. Converts sound waves into an electrical signal. Extremely tiny, handle with care. | Small black square SMD component. Pin 1 is marked, alignment CRITICAL. One per MIC PCB. This is the bottom view, since the terminals are placed on the bottom.

!

CRITICAL — Orientation matters on all ICs and MOSFETs. A single misaligned leg can destroy the component. Always verify pin 1 under magnification before applying solder.

### 2.4 Connectors & Through-Hole Parts

ID | Part Name | What It Does | How to Identify It
J1 | 2-pin Battery Connector | Connects the LiPo battery to the BMS PCB. Red = positive (+), Black = negative (−). Never reverse this. | JST PH 2.0mm or screw terminal (see your PCB). Located at 'Battery' label on BMS PCB.
J2 | 2-pin HiLetgo Connector | Battery input to the HiLetgo charge+boost module. | Matches J1 pitch. At 'HiLetgo' label on BMS PCB.
J3 | 2-pin HiLetgo 5V Out | 5V output from the HiLetgo module back to the BMS rail. | At 'HiLetgo 5V' label on BMS PCB.
J4 | 2-pin Bela 5V | Delivers 5V from BMS to the Bela Cape PCB. | At 'Bela 5V' on BMS, connects to '5V Input' on Bela Cape.
J5 | 2-pin 3.3V OBCI | Powers the OpenBCI board with 3.3V from the BMS LDO. | At '3.3V OBCI' on BMS PCB.
J6 | 2-pin Mic 3.3V | Supplies 3.3V mic bias rail from BMS to Bela Cape. | At 'Mic 3.3V' on BMS, connects to 'MIC VD2' on Bela Cape.
J7 | 4-pin R-Mic Connector | Carries 5V, 3.3V, GND, and audio signal to Right MIC PCB. | At 'R-Mic' on Bela Cape. 4 pins, match all 4 carefully.
J8 | 4-pin L-Mic Connector | Carries 5V, 3.3V, GND, and audio signal to Left MIC PCB. | At 'L-Mic' on Bela Cape. 4 pins , mirror of J7.
P1 | 36-pin Header (BeagleBone P8) | Connects Bela Cape to BeagleBone P8 expansion port , carries audio data and control signals. | 2×18 header, 2.54mm pitch. Long pins face down into BeagleBone.
P2 | 36-pin Header (BeagleBone P9) | Connects Bela Cape to BeagleBone P9 expansion port , carries power and I2C signals. | 2×18 header, identical to P1. Pin 1 alignment critical.

nEEGlace Build Guide v1.0Page 5

J9 | 3.5mm Audio Jack | Stereo TRS audio output , plug in headphones or recording interface here. | Standard 3.5mm through-hole jack. Goes in the 'Audio Out' position on Bela Cape.
SW1 | Power Switch | Main system on/off switch. Always switch OFF before wiring. Always switch ON only after everything is connected. | Through-hole slider or toggle switch. On BMS PCB.
MOD 1 | HiLetgo Module | Pre-built charge+boost module. Charges the LiPo battery via USB-C and boosts battery voltage to stable 5V. The heart of the power system. | Small black PCB module. USB-C port visible. Mount onto J2 + J3 connectors.

nEEGlace Build Guide v1.0Page 6

## SECTION 3 : System Overview

SIGNAL FLOW DIAGRAM

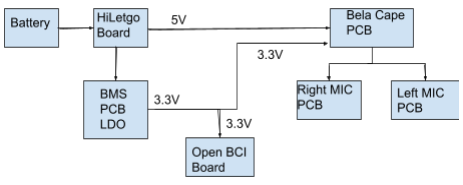
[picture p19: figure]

BMS PCB | Battery Management System. Receives raw battery voltage, protects against overcharge via MOSFET [U2], boosts/regulates to 5V via HiLetgo module [MOD1], steps down to 3.3V via LDO [U1]. Has the power switch [SW1].
Bela Cape PCB | Audio processor cape for BeagleBone. Receives 5V + 3.3V, distributes mic power to both MIC PCBs, outputs stereo audio at 3.5mm jack [J9], sends bio-signals via VD1 divider to OpenBCI. Slots onto BeagleBone via headers [P1][P2].
MIC PCBs (×2) | Left and Right microphone boards. Each contains one MEMS mic [MIC], one op-amp [U3], and passive filter components. Powered by 5V + 3.3V from Bela Cape. Output goes back to Bela Cape as left/right stereo audio.

nEEGlace Build Guide v1.0Page 7

## SECTION 4 — BMS PCB

This is Board 1 of 4. It controls power for the entire system.

TIP

Look at Fig.1 (BMS PCB layout) and identify the labeled areas: Mic 3.3V, Bela 5V, Battery, HiLetgo, LDO, MOSFET, Switch, 3.3V OBCI, HiLetgo 5V.

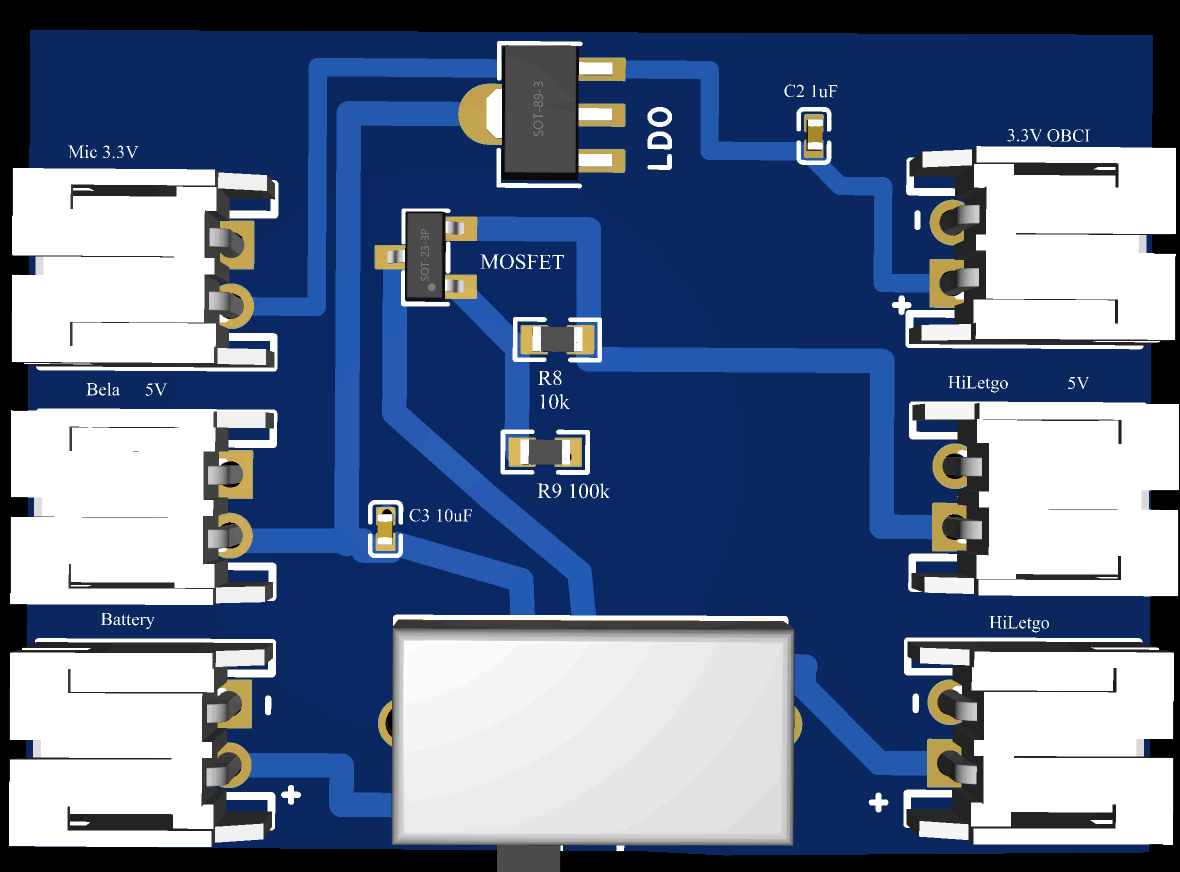
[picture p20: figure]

Fig.1: 3D view of BMS PCB

1. Verify that the preassembled BMS PCB looks exactly as in Fig.1.
2. Verify the values of gate-Bias Resistors [R8] and [R9] to be exactly 10kΩ and 100kΩ using a multimeter.
3. Verify the decoupling capacitors C2 and C3 using a multimeter. Set your digital multimeter to the Capacitance mode (indicated by the symbol( -||- or F) to read microfarads (μ F) or nanofarads (nF). If your multimeter lacks this setting, you can use the Resistance mode (Ω) as an alternative to test if the capacitor charges and discharges properly. If you are operating it in Resistance mode, if the measured value is more than 1MΩ, then the capacitor is working perfectly, and if it's less than 1MΩ or 0Ω, then the capacitor might be damaged.
4. Flip the board, check the switch pins from the back. Check that pins are fully through and contacts are not bridged. Confirm switch toggles between two positions with a satisfying click. Toggle to the OFF position before continuing.
5. Verify that all the connectors are soldered properly, flip the board, and check the connector pins from the back. Check that pins are fully through and contacts are not bridged.
4.1

Mount HiLetgo Module [MOD1]
Pre-built charge and boost module — no soldering required on the module itself
6. Solder red and black wires in the respective battery and 5V terminals labelled + and -.
7. Orient the HiLetgo module with USB-C port facing outward (away from board edge or toward accessible side per your enclosure plan).
8. Plug module's battery wires into [J2] — match polarity carefully (+/−).
9. Plug module's 5V output wires into [J3] — match polarity.
10. Confirm the module is secure. Do NOT power on yet.

BMS PCB — Assembly Checklist:
- R8 (10kΩ) and R9 (100kΩ) soldered and correct
- C2 (1µF) and C3 (10µF) soldered
- MOSFET [U2] orientation verified against schematic
- LDO [U1] orientation verified, tab soldered
- All 6 edge connectors J1–J6 soldered and labeled
- Switch [SW1] soldered and in the OFF position
- HiLetgo module [MOD1] plugged into J2 + J3

nEEGlace Build Guide v1.0Page 8

## SECTION 5 — Bela Cape PCB Assembly

This is Board 2 of 4. It is the audio heart of the system, running on a BeagleBone single-board computer. The PCB image shown in Fig.2 (3D view) is this board.
11. Verify that the preassembled Bela PCB looks exactly as in Fig.2.
12. Verify the values of MIC-Bias Resistors [R8] and [R9] to be exactly 2.2kΩ each using a multimeter.
13. Verify the MIC Bias capacitors C2 and C3 using a multimeter. Set your digital multimeter to the Capacitance mode (indicated by the symbol( -||- or F) to read microfarads (μ F) or nanofarads (nF). If your multimeter lacks this setting, you can use the Resistance mode (Ω) as an alternative to test if the capacitor charges and discharges properly. If you are operating it in Resistance mode, if the measured value is more than 1MΩ, then the capacitor is working perfectly, and if it's less than 1MΩ or 0Ω, then the capacitor might be damaged.
14. Verify the values of Voltage Divider Resistors [R3] and [R4] to be exactly 1MΩ and 10kΩ each using a multimeter.
15. Flip the board, check the Audio jack pins from the back. Check that pins are fully through and contacts are not bridged.
16. Verify that all the connectors are soldered properly, flip the board, and check the connector pins from the back. Check that pins are fully through and contacts are not bridged.

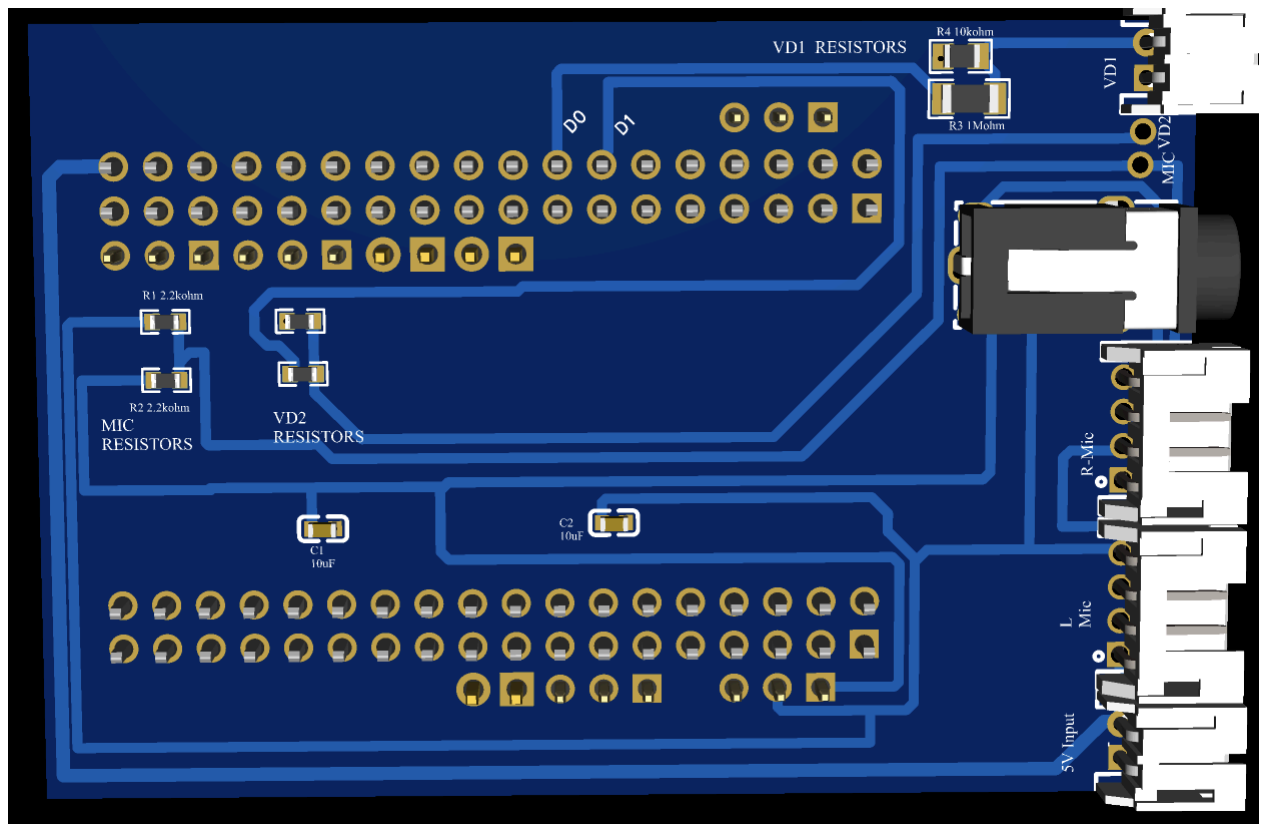
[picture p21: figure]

Fig.2: 3D view of Bela Cape

Bela Cape PCB — Assembly Checklist:
- R1, R2 (2.2kΩ each) soldered at MIC RESISTORS area
- C1, C2 (10µF each) soldered next to R1, R2
- R3 (1MΩ) upper VD1 pad, R4 (10kΩ) lower VD1 pad
- VD2 resistors per schematic
- All 6 edge connectors soldered and labeled correctly
- Audio jack [J9] seated flat and all pins soldered
- Headers P1 & P2 soldered with BeagleBone as alignment jig

nEEGlace Build Guide v1.0Page 9

## SECTION 6 — Left MIC PCB & Right MIC PCB Assembly

These are Boards 3 and 4 of 4. Both boards are IDENTICAL; Refer to Fig.3 for the 3D layout: you can see the Mic, Op-Amp, passives, and 4-pin output connector.

TIP

Fig.3 shows the 3D view of the MIC PCB. Locate: top-left = 10kΩ resistors, top-center = 100kΩ, left =
10µF caps, center = Op-Amp IC, bottom-left gray square = MEMS Microphone, right edge = 4-pin output connector.
17. Verify that the preassembled MIC PCBs look exactly as in Fig.3.
18. Verify the values of decoupling Resistors [R5a] and [R5b], [R6] to be exactly 10kΩ, 10kΩ, and 100kΩ, respectively, each using a multimeter.
19. Verify the decoupling capacitors C4a, C4b and C5 using a multimeter. Set your digital multimeter to the Capacitance mode (indicated by the symbol( -||- or F) to read microfarads (μ F) or nanofarads (nF). If your multimeter lacks this setting, you can use the Resistance mode (Ω) as an alternative to test if the capacitor charges and discharges properly. If you are operating it in Resistance mode, if the measured value is more than 1MΩ, then the capacitor is working perfectly, and if it's less than 1MΩ or 0Ω, then the capacitor might be damaged.
20. Flip the board, check the Audio jack pins from the back. Check that pins are fully through and contacts are not bridged.
21. Verify that all the connectors are soldered properly, flip the board, and check the connector pins from the back. Check that pins are fully through and contacts are not bridged.

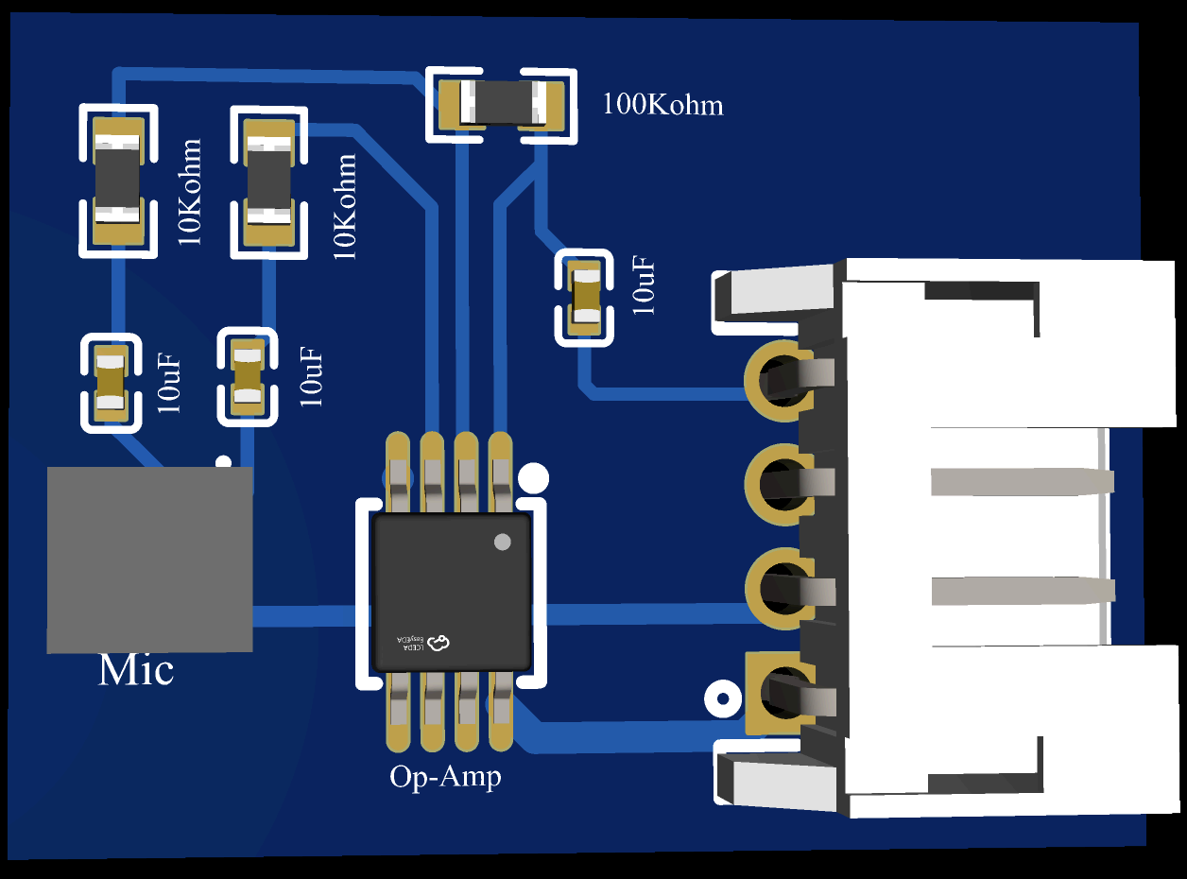
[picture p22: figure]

Fig.3: 3D view of the MEMS mic PCB

Both MIC PCBs — Checklist (do for EACH board):
- R5a and R5b (10kΩ each) soldered — values matched
- R6 (100kΩ) soldered at mic bias position
- C4a, C4b, C5 (10µF each) soldered
- Op-amp [U3] pin 1 aligned to PCB marker, all 8 legs soldered cleanly
- MEMS mic [MIC] pin 1 aligned, sound port facing outward
- 4-pin output connector soldered, pin order confirmed

nEEGlace Build Guide v1.0Page 10

## SECTION 7 — System Wiring (Connecting All 5 Boards)

All four boards are now assembled. This section connects them together. Work in the exact order shown. Do not connect the battery until Step 7.1 says to.

!

BEFORE STARTING: Confirm switch [SW1] on the BMS PCB is in the OFF position. Confirm battery is NOT connected to J1.
7.1

Connect Battery to BMS [J1]
First wiring connection — still OFF

Connect the LiPo battery cable to the BMS connector [J1].
- Red wire → (+) pin of J1
- Black wire → (−) pin of J1
- Double-check polarity. Reversed battery connection = damaged BMS.
- Confirm switch [SW1] is OFF. Nothing should power on yet.
7.2

Connect BMS to Bela Cape: 5V Power [J4 → 5V Input]
5V + GND to Bela Cape

Run a 2-pin cable from BMS [J4] labeled 'Bela 5V' to Bela Cape connector labeled '5V Input'.
- Pin 1 (5V) connects to 5V
- Pin 2 (GND) connects to GND
- Match wire colors if using pre-made jumper — red=5V, black=GND
7.3

Connect BMS to Bela Cape: Mic Bias [J6 → MIC VD2]
3.3V mic power

Run a 2-pin cable from BMS [J6] labeled 'Mic 3.3V' to Bela Cape connector labeled 'MIC VD2'.
- This rail powers the microphone bias networks on both MIC PCBs
7.4

Connect BMS to OpenBCI [J5 → OpenBCI 3.3V In]
Powers the brain-signal board

Run a 2-pin cable from BMS [J5] labeled '3.3V OBCI' to the OpenBCI board's 3.3V power input terminal.
- Confirm OpenBCI's power input polarity matches — OpenBCI documentation specifies pin order
7.5

Connect Bela Cape VD1 → OpenBCI Signal Input
Bio-signal input to OpenBCI

The VD1 divider (R3 + R4) outputs a 33mV scaled bio-signal. Wire it to OpenBCI's analog signal input.
- VD1 (+) terminal → OpenBCI channel
- VD1 (−) terminal → OpenBCI Bias

nEEGlace Build Guide v1.0Page 11

7.6

Connect Bela Cape → Right MIC PCB [R-Mic → J7]
4-wire connection — power and audio
Wire # | Bela Cape R-Mic | Right MIC PCB | Signal
1 | 5V | 5V | 5V Power
2 | 3.3V | 3.3V | Mic bias
3 | GND | GND | Ground
4 | R (Right audio) | Right MIC out | Audio signal
7.7

Connect Bela Cape → Left MIC PCB [L-Mic → J8]
4-wire connection — mirror of Step 7.7

Repeat Step 7.7 exactly, substituting 'L-Mic' connector on Bela Cape, and 'Left MIC PCB' as destination. Pin mapping is identical — just the audio channel is Left instead of Right.
7.8

Seat Bela Cape onto BeagleBone [P1 + P2]
Final board-to-board mating
22. Locate pin 1 marker on BeagleBone P8 header — usually a square pad or a dot on silkscreen.
23. Align Bela Cape P1 header pin 1 with BeagleBone P8 pin 1. They must match.
24. Press firmly and evenly straight down. Do NOT rock sideways — bent pins cannot be re-straightened easily.
25. Repeat for P2 onto BeagleBone P9.
26. Confirm both connectors are fully seated — no daylight visible between connector bodies.
7.9

Connect Audio Output [J9]
Plug in headphones, amp, or recording interface

Plug a 3.5mm TRS cable into the audio jack [J9] on the Bela Cape. This is your stereo audio output. No polarity to worry about — just push it in until it clicks.

nEEGlace Build Guide v1.0Page 12

## SECTION 8 — Power-On & Verification

Do not skip this section. Test each stage before moving to the next. If something is wrong, catching it early saves hours of debugging.
8.1

Initial Power-On
Flip [SW1] to ON for the first time
27. Confirm all wiring from Section 7 is complete.
28. Confirm switch [SW1] is currently OFF.
29. Flip the switch to ON.
30. Immediately check: does anything smell like burning? See any smoke? If yes — SWITCH OFF IMMEDIATELY and look for solder bridges on the BMS.
31. If no smell/smoke: continue to voltage checks.

### 8.2 Voltage Verification Table

Use a multimeter in DC voltage mode. Black probe to any GND point. Measure at each connector:

Test Point | Expected Voltage | Tolerance | If Wrong...
BMS J4 'Bela 5V' connector | 5.0 V | ± 0.2V | Check HiLetgo module, check J3 wiring
BMS J5 '3.3V OBCI' connector | 3.3 V | ± 0.1V | Check LDO [U1] orientation, check C2/C3
BMS J6 'Mic 3.3V' connector | 3.3 V | ± 0.1V | Same LDO check as above
Bela Cape '5V Input' connector | 5.0 V | ± 0.2V | Check cable from J4 to 5V Input
Bela Cape 'MIC VD2' connector | 3.3 V | ± 0.1V | Check cable from J6 to MIC VD2
Right MIC PCB 5V pin | 5.0 V | ± 0.2V | Check R-Mic 4-pin cable
Right MIC PCB 3.3V pin | 3.3 V | ± 0.1V | Check R-Mic 4-pin cable pin 2
Left MIC PCB 5V pin | 5.0 V | ± 0.2V | Check L-Mic 4-pin cable

### 8.3 Audio Verification

32. Connect Bela to your computer via USB or network. Open the Bela web IDE at bela.local.
33. Confirm Bela boots successfully, the status LED on BeagleBone should blink, and bela. local should respond in the browser.
34. Load the 'passthrough' example from Bela IDE. This routes the mic input directly to the audio output.
35. Click Run. Speak near the Left MIC PCB, you should hear your voice in the headphones on the Left channel.
36. Speak near the Right MIC PCB; you should hear your voice on the Right channel.
37. If one channel is silent, see Troubleshooting Section 9.
38. Open the Bela 'scope' tool. Both left and right channels should show waveforms when you make noise.

nEEGlace Build Guide v1.0Page 13

### 8.4 Charging Test

39. Connect a USB-C cable to the HiLetgo module [MOD1].
40. The system should power DOWN automatically. This is correct behavior, designed to prevent simultaneous charge+discharge.
41. Disconnect USB-C. The system should power back ON automatically within a few seconds.

TIP

If the system does NOT power off when the USB is connected, the MOSFET [U2] is likely backwards. Desolder and re-orient, checking against the schematic.

nEEGlace Build Guide v1.0Page 14

## SECTION 9 — Troubleshooting Guide

Something not working? This table covers the most common problems and their fixes.

Symptom | Likely Cause | Fix / Check
No power anywhere, nothing lights up | Switch [SW1] off, dead battery, or battery connector [J1] reversed | Flip the switch ON. Check battery voltage (≥3.7V). Verify J1 polarity.
The system won't power on even with a fresh battery | MOSFET [U2] installed backwards | Desolder U2 and re-orient. Check gate (G), drain (D), and source (S) against the schematic.
The system never powers off when a USB-C is plugged in | MOSFET [U2] reversed, or R8 (10kΩ) and R9 (100kΩ) swapped | Desolder U2 and check orientation. Confirm R8='103' and R9='104'.
No 3.3V output at J5 or J6 | LDO [U1] orientation wrong, or C2/C3 missing/bridged | Verify LDO IN-GND-OUT pin order against the MCP1700T datasheet. Check capacitors for solder bridges.
One MIC channel completely silent | Broken 4-pin cable, wrong pin order, or bad op-amp solder joint | Check cable continuity with a multimeter. Inspect op-amp [U3] under magnifier for lifted pins or bridges.
Both MIC channels silent | Missing 3.3V on MIC VD2, or C1/C2 missing on Bela Cape | Measure voltage at the MIC VD2 connector. Check the J6 cable. Inspect C1 and C2 on Bela Cape.
Audio sounds distorted or buzzy | R1/R2 (2.2kΩ) values wrong, or C1/C2 poor solder joints | Measure R1/R2 with a multimeter (remove power first). Re-flow C1/C2 solder joints.
OpenBCI receives no signal from VD1 | R3/R4 swapped, or VD1 connector wired backwards | Verify R3=1MΩ (upper pad) and R4=10kΩ (lower pad). Check VD1 connector +/− polarity.
BeagleBone won't boot / no bela.local | Headers P1/P2 misaligned or not fully seated | Press the Bela Cape firmly down onto the BeagleBone. Look for bent pins on P8/P9.
MEMS mic makes crackle/static noise | Sound port blocked or C4/C5 missing | Check mic port for flux residue — clean gently with IPA and thin brush. Verify C4a, C4b, C5 present.

nEEGlace Build Guide v1.0Page 15

## SECTION 10 — Quick Reference Card

Cut out or bookmark this page. It summarizes every component ID, its location, and critical orientation notes.

### All Component IDs at a Glance

ID | Part | Value | Location | Critical Note
R1 | Resistor | 2.2 kΩ | Bela Cape, MIC RESISTORS | Non-polar, SMD
R2 | Resistor | 2.2 kΩ | Bela Cape, MIC RESISTORS | Non-polar, SMD
R3 | Resistor | 1 MΩ | Bela Cape, VD1 upper | Marked 105 — upper pad
R4 | Resistor | 10 kΩ | Bela Cape, VD1 lower | Marked 103 — lower pad
R5a/b | Resistor | 10 kΩ ×2 | MIC PCB | Op-amp gain — matched pair
R6 | Resistor | 100 kΩ | MIC PCB | Mic bias, marked 104
R7 | Resistor | per schematic | Bela Cape | Check the schematic for values
R8 | Resistor | 10 kΩ | BMS PCB | Gate bias, marked 103
R9 | Resistor | 100 kΩ | BMS PCB | Gate bias, marked 104 — do not swap with R8
C1 | Capacitor | 10 µF | Bela Cape | Non-polar SMD ceramic
C2 | Capacitor | 1 µF | BMS PCB | Non-polar SMD ceramic
C3 | Capacitor | 10 µF | BMS PCB | Non-polar SMD ceramic
C4a/b | Capacitor | 10 µF ×2 | MIC PCB | Op-amp decoupling
C5 | Capacitor | 10 µF | MIC PCB | Mic bias decoupling
U1 | LDO | MCP1700T-3302 | BMS PCB | SOT-89-3: verify IN/GND/OUT
U2 | MOSFET | SSI2301CDS-T1-E3 | BMS PCB | SOT-23-3P: G/S/D — CRITICAL orientation
U3 | Op-Amp | per BOM | MIC PCBs | 8-pin SMD: pin 1 = dot/notch
MIC | MEMS Mic | MMICT390200012 | MIC PCBs | Sound port faces outward — critical
SW1 | Switch | Power | BMS PCB | OFF before any wiring
MOD1 | HiLetgo | 5V boost + charger | BMS PCB | USB-C for charging
P1 | Header | 2×18 / 36-pin | Bela Cape | BeagleBone P8 — use BB as jig
P2 | Header | 2×18 / 36-pin | Bela Cape | BeagleBone P9 — use BB as jig

### Wiring Connections Summary

Step | From | To | Signal
7.1 | Battery | BMS J1 [Battery] | Battery power
7.3 | BMS J4 [Bela 5V] | Bela Cape [5V Input] | 5V + GND
7.4 | BMS J6 [Mic 3.3V] | Bela Cape [MIC VD2] | 3.3V mic bias
7.5 | BMS J5 [3.3V OBCI] | OpenBCI power input | 3.3V + GND
7.6 | Bela Cape [VD1] | OpenBCI signal input | 33mV bio-signal
7.7 | Bela Cape [R-Mic] | Right MIC PCB | 5V, 3.3V, GND, audio
7.8 | Bela Cape [L-Mic] | Left MIC PCB | 5V, 3.3V, GND, audio
7.9 | Bela Cape P1 | BeagleBone P8 | 36-pin expansion
7.9 | Bela Cape P2 | BeagleBone P9 | 36-pin expansion

## Assembly Complete!

nEEGlace Build Guide v1.0Page 16

You have built the nEEGlace.
For firmware, Bela programming, and signal processing — see your project documentation.

nEEGlace Build Guide v1.0Page 17

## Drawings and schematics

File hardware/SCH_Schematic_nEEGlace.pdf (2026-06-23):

## Right MIC PCB

## Bela Cape PCB

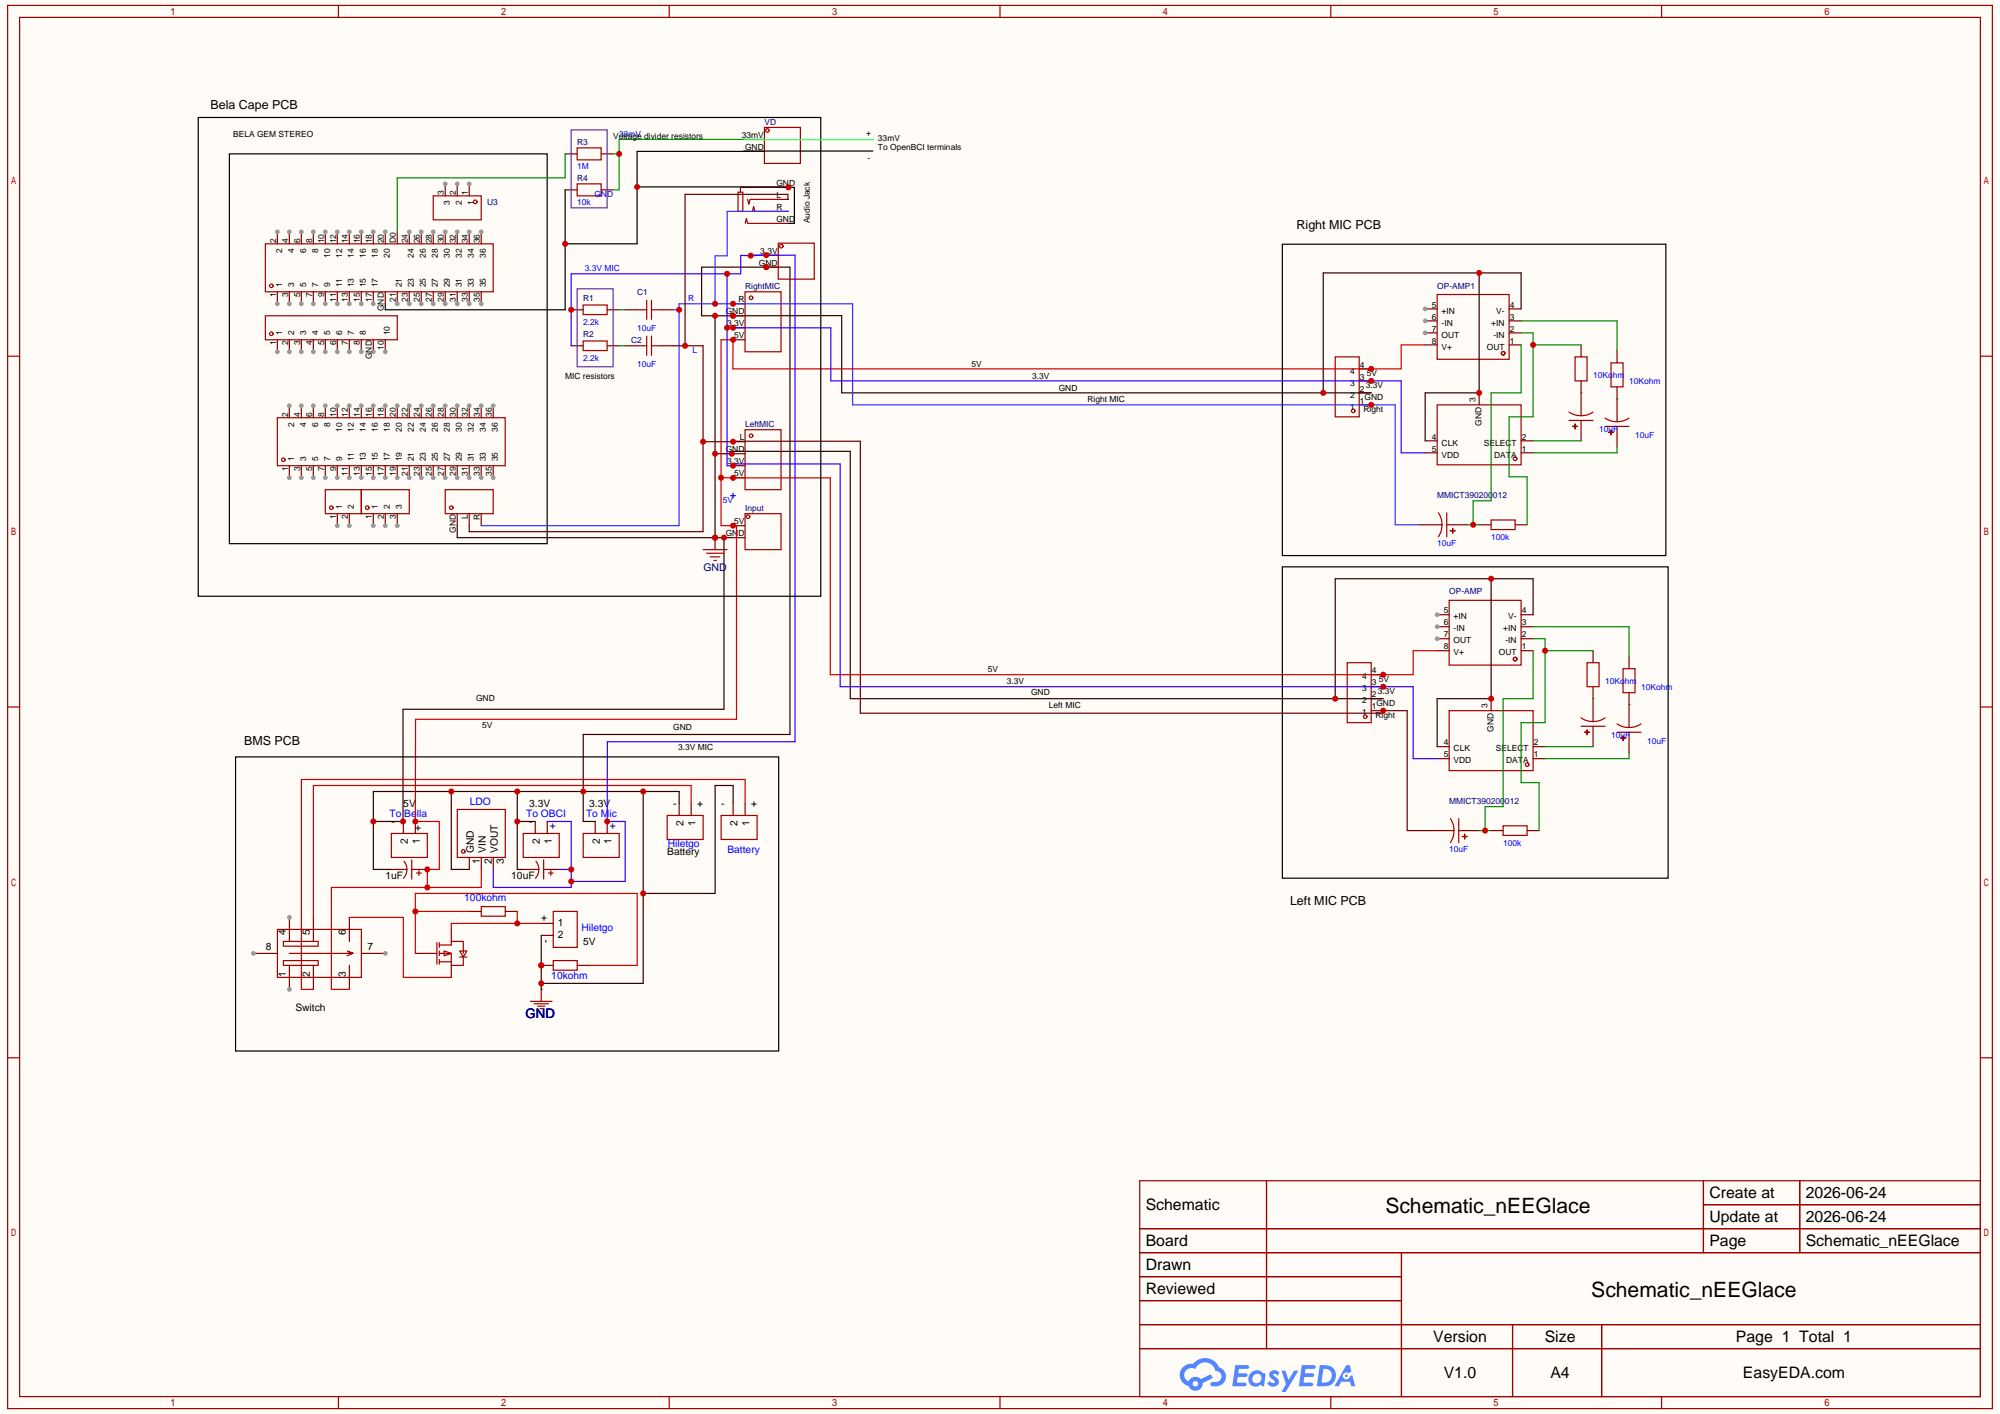
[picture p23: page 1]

GND
3.3V

Schematic | Schematic_nEEGlace | Create at | 2026-06-24

Update at | 2026-06-24

Board | | Page | Schematic_nEEGlace
Drawn | | Schematic_nEEGlace
Reviewed

Version | Size | Page 1 Total 1
V1.0 | A4 | EasyEDA.com

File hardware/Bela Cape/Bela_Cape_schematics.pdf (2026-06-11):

L

# GND

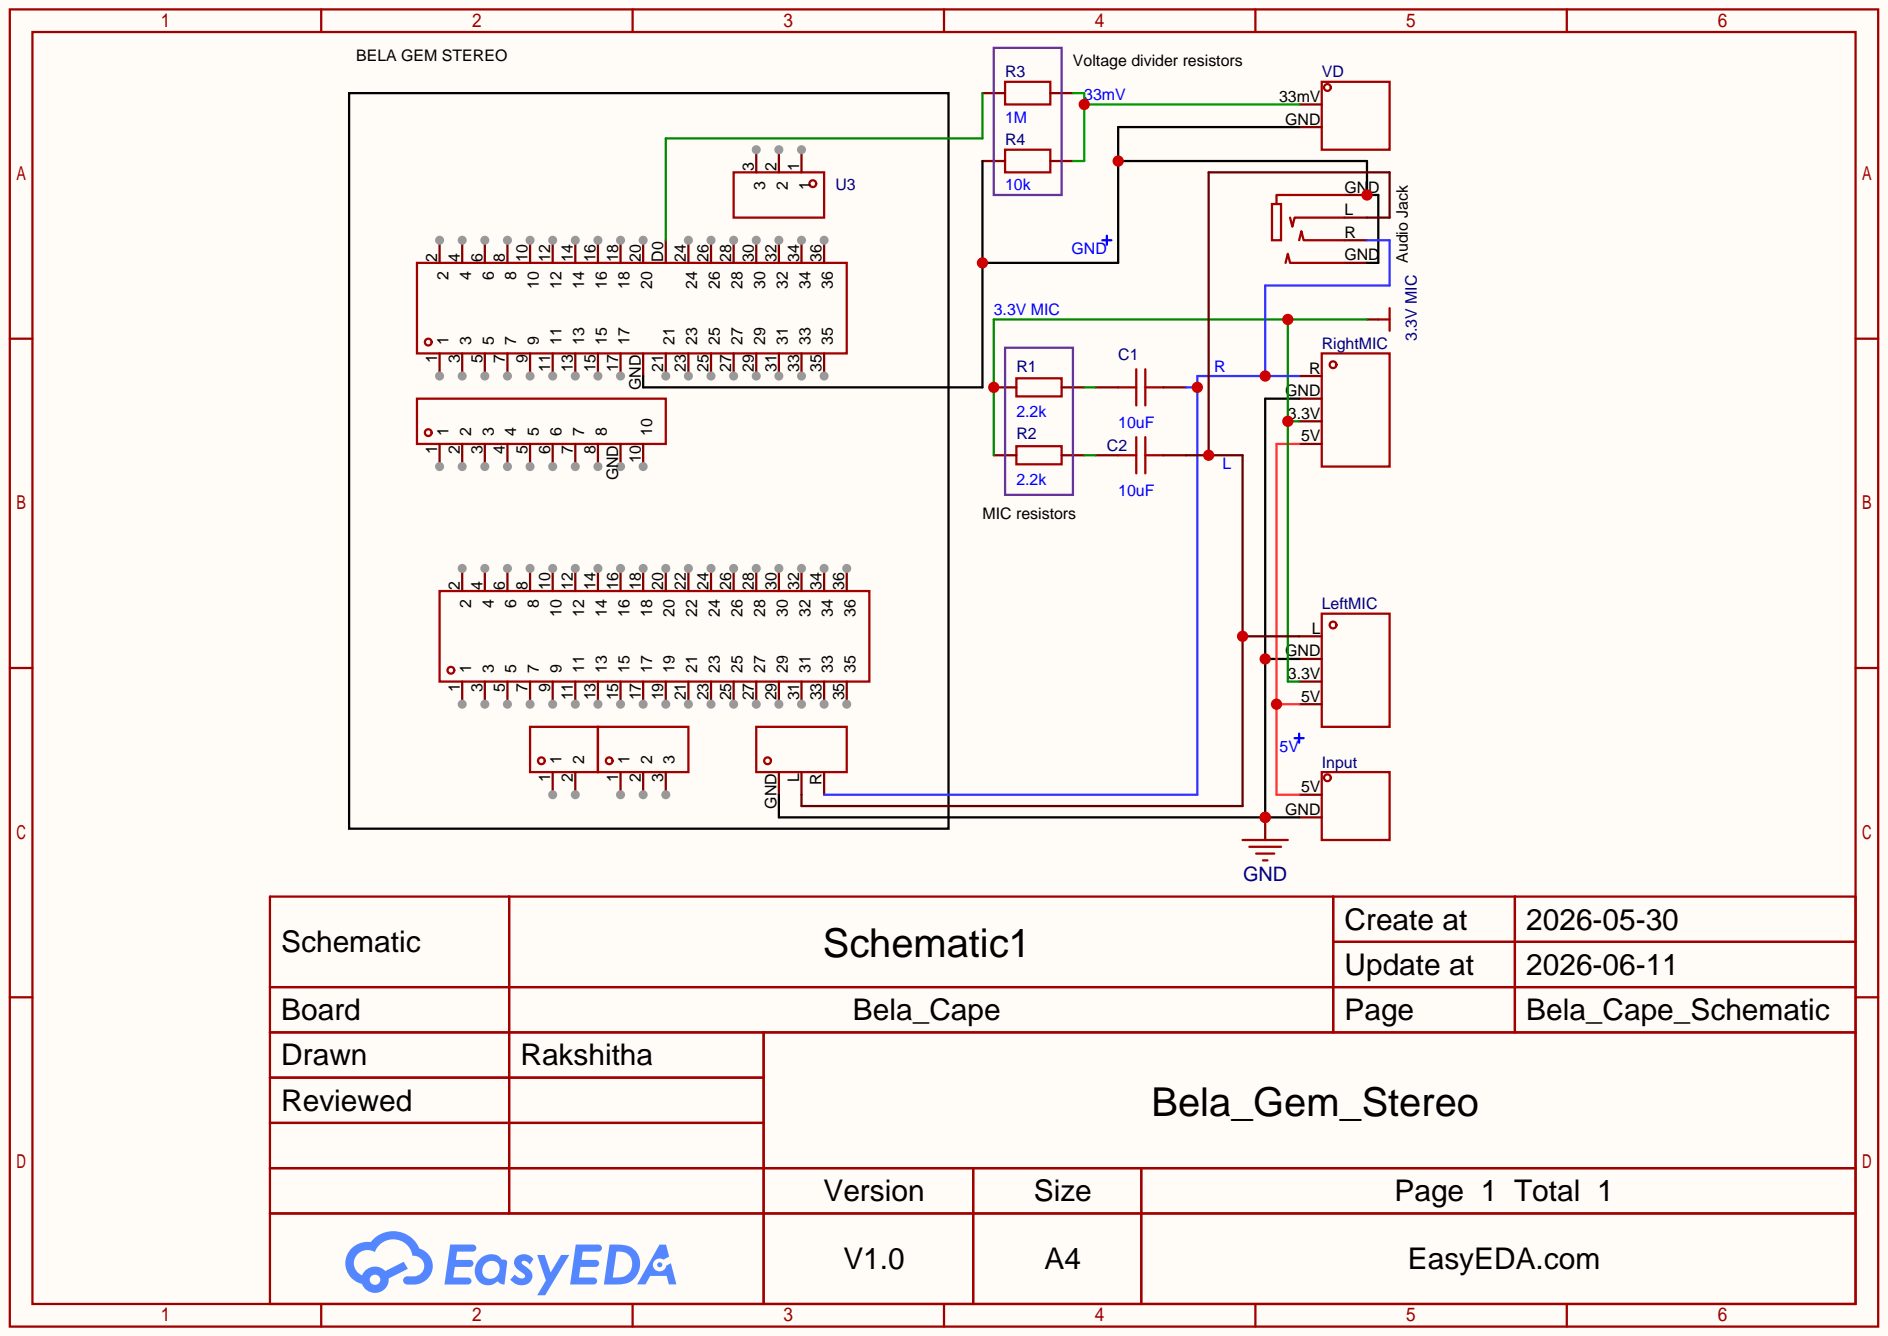
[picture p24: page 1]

Schematic | Schematic1 | Create at | 2026-05-30

Update at | 2026-06-11

Board | Bela_Cape | Page | Bela_Cape_Schematic
Drawn | Rakshitha | Bela_Gem_Stereo
Reviewed

Version | Size | Page 1 Total 1
V1.0 | A4 | EasyEDA.com

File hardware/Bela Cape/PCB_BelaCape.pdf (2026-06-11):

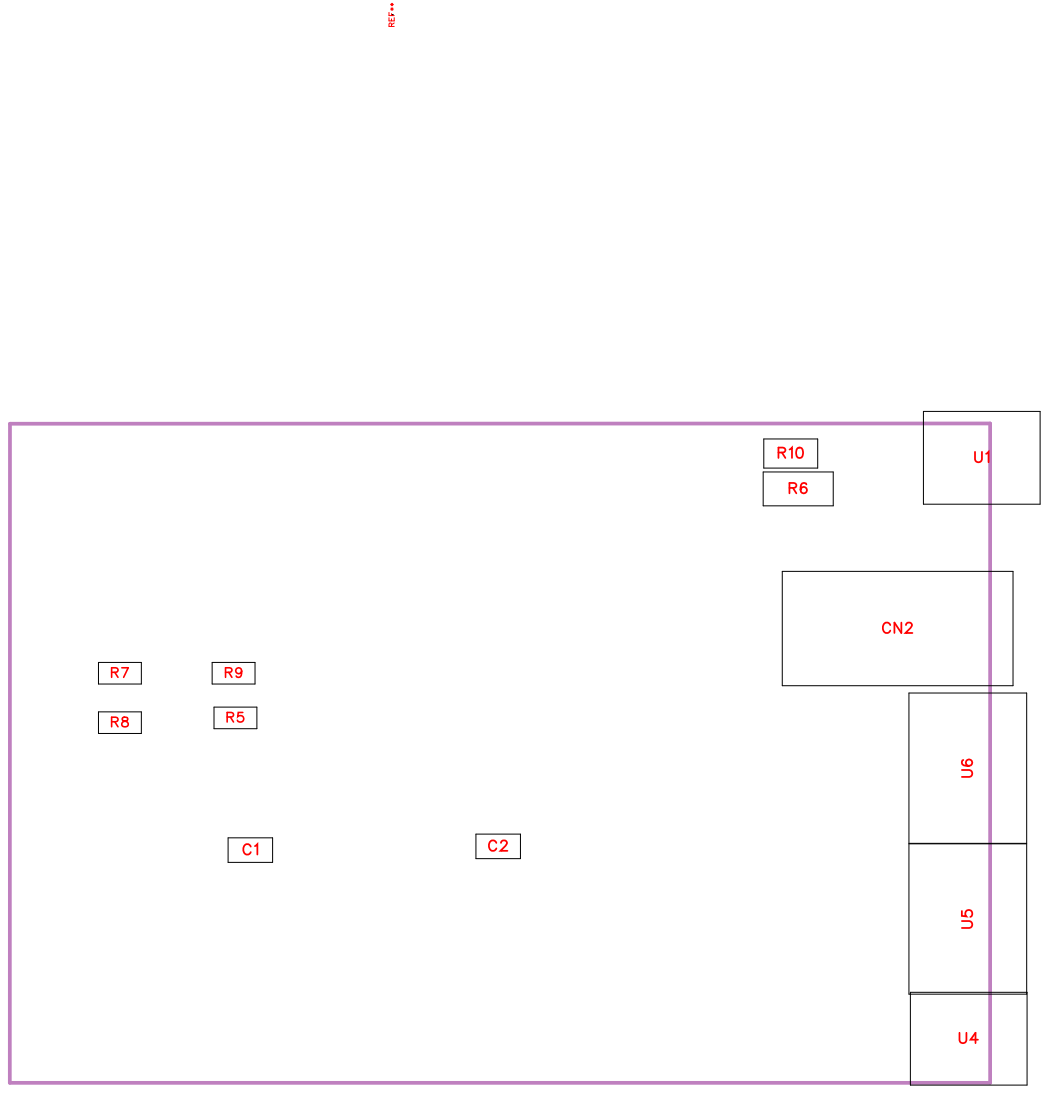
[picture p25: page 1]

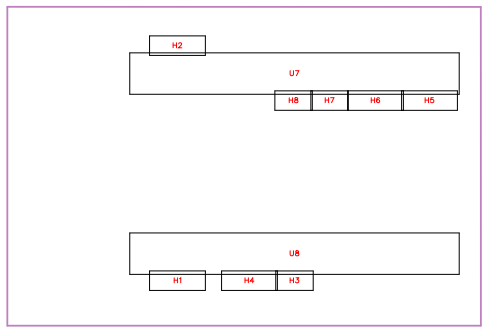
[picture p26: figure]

No. | Quantity | Comment | Designator | Footprint | Value | Manufacturer Part | Manufacturer | Supplier Part | Supplier | Add into BOM
1 | 2 | 10uF | C1,C2 | C0603 | 10uF | CL10A106KP 8NNNC | SAMSUNG( ) 三星 | C19702 | LCSC | yes
2 | 1 | PJ-322环保 | CN2 | AUDIO-TH_ HOOYA_PJ-322 | | PJ-322环保 | HOOYA(皓宇 ) 电子 | C2939185 | LCSC | yes
3 | 5 | 1x3单排直针 2.54mm间距 | H1,H2,H4,H5,H6 | HDR-TH_3P-P2.54-V-M | | 1x3单排直针 2.54mm间距 | | C990001740 2 | LCSC | yes
4 | 3 | HX PH254-0 1-02-Z-L11.5 male header connector | H3,H7,H8 | HDR-TH_2P-P2.54-V-M | | HX PH254-0 1-02-Z-L11.5 male header connector | hanxia(韩下 ) | C52016390 | LCSC | yes
5 | 4 | 2.2k | R5,R7,R8,R9 | R0603 | 2.2k | FRC0603F22 01TS | FOJAN(富捷 ) | C2907005 | LCSC | yes
6 | 1 | 1M | R6 | R1206 | 1M | 1206W4F100 4T5E | UNI-ROYAL( 厚声 ) | C17927 | LCSC | yes
7 | 1 | 10k | R10 | R0805 | 10k | FRC0805J10 3TS | FOJAN(富捷 ) | C2930231 | LCSC | yes
8 | 1 | PocketBeagl e3D_for_Bel amini | REF** | Bela:PocketB eagle3D_for_ Belamini | | | | | | yes
9 | 2 | S2B-PH-K-S( LF)(SN) | U1,U4 | CONN-TH_S 2B-PH-K-S-L F-SN | | S2B-PH-K-S( LF)(SN) | JST | C173752 | LCSC | yes
10 | 2 | S4B-PH-K-S( LF)(SN) | U5,U6 | CONN-TH_4 P-P2.00_S4B -PH-K-S-LF-SN | | S4B-PH-K-S( LF)(SN) | JST | C157926 | LCSC | yes
11 | 2 | HMNDSH25-1801A121TB B | U7,U8 | HDR-TH_36 P-P2.54-V-F-R2-C18-S2.5 4-2 | | HMNDSH25-1801A121TB B | | C990010862 9 | LCSC | yes

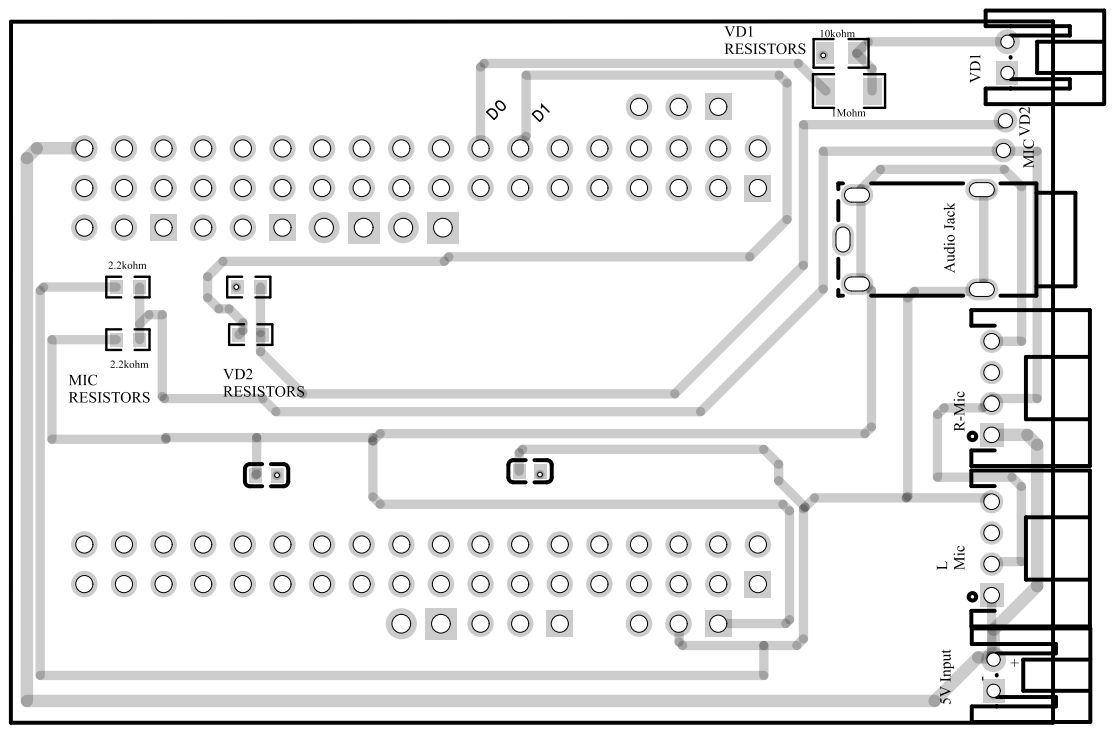
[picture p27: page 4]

5V Input Audio Jack LMic R-Mic

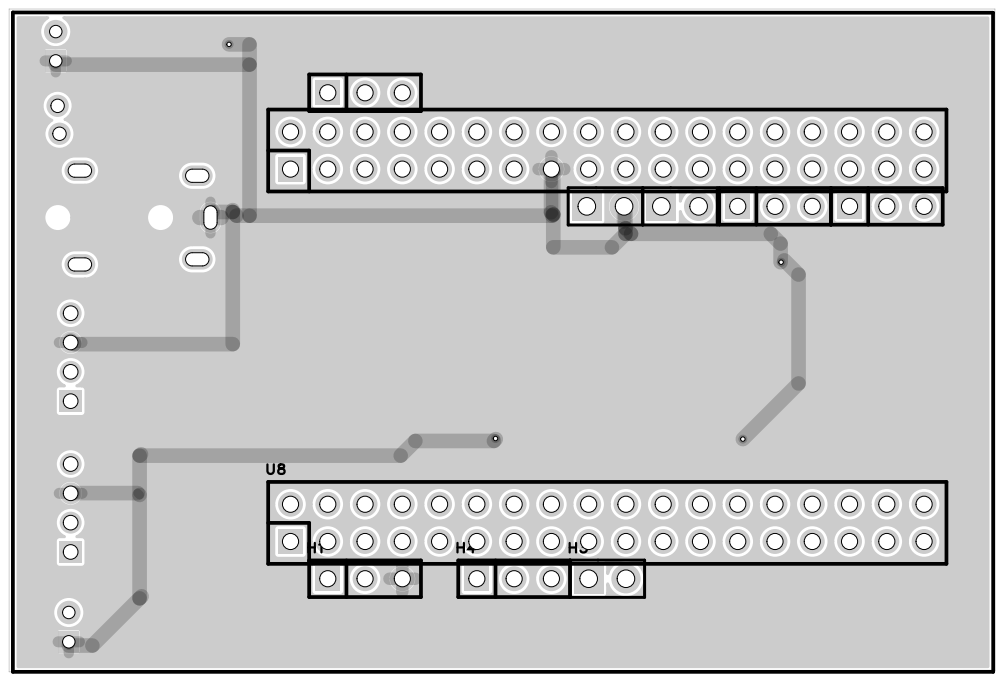
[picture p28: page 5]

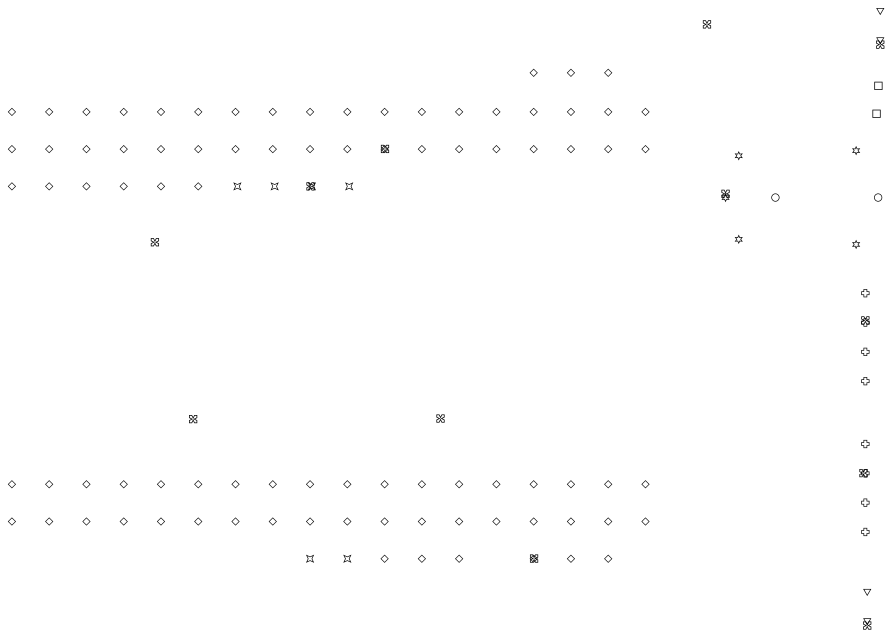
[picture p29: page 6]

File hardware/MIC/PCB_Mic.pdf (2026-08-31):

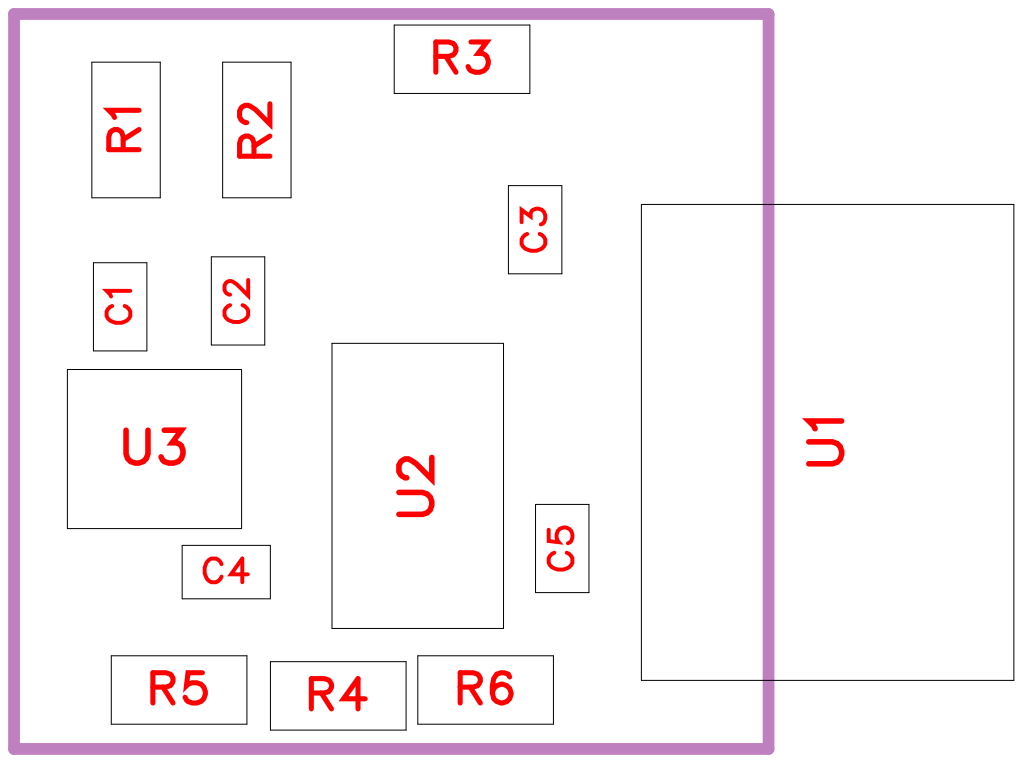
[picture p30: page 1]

No. | Quantity | Comment | Designator | Footprint | Value | Manufacturer Part | Manufacturer | Supplier Part | Supplier | Add into BOM
1 | 3 | 10nF | C1,C2,C3 | C0402 | 10nF | FCC0402B10 3K500AT | FOJAN(富捷 ) | C5137480 | LCSC | yes
2 | 2 | 100nF | C4,C5 | C0402 | 100nF | CL05B104KB 54PNC | SAMSUNG( ) 三星 | C307331 | LCSC | yes
3 | 6 | 100k | R1,R2,R3,R4,R5,R6 | R0603 | 100k | FRC0603J10 4 TS | FOJAN(富捷 ) | C2907088 | LCSC | yes
4 | 1 | S4B-PH-K-S( LF)(SN) | U1 | CONN-TH_4 P-P2.00_S4B -PH-K-S-LF-SN | | S4B-PH-K-S( LF)(SN) | JST | C157926 | LCSC | yes
5 | 1 | LM358ST | U2 | MSOP-8_L3. 0-W3.0-P0.6 5-LS5.0-BL | | LM358ST | ST(意法半导 体) | C54867 | LCSC | yes
6 | 1 | ICS-40638 | U3 | MIC-SMD_L3 .5-W2.7_MN R8065S332 MT | | ICS-40638 | TDK InvenSe nse(应美盛 ) | C3171798 | LCSC | yes

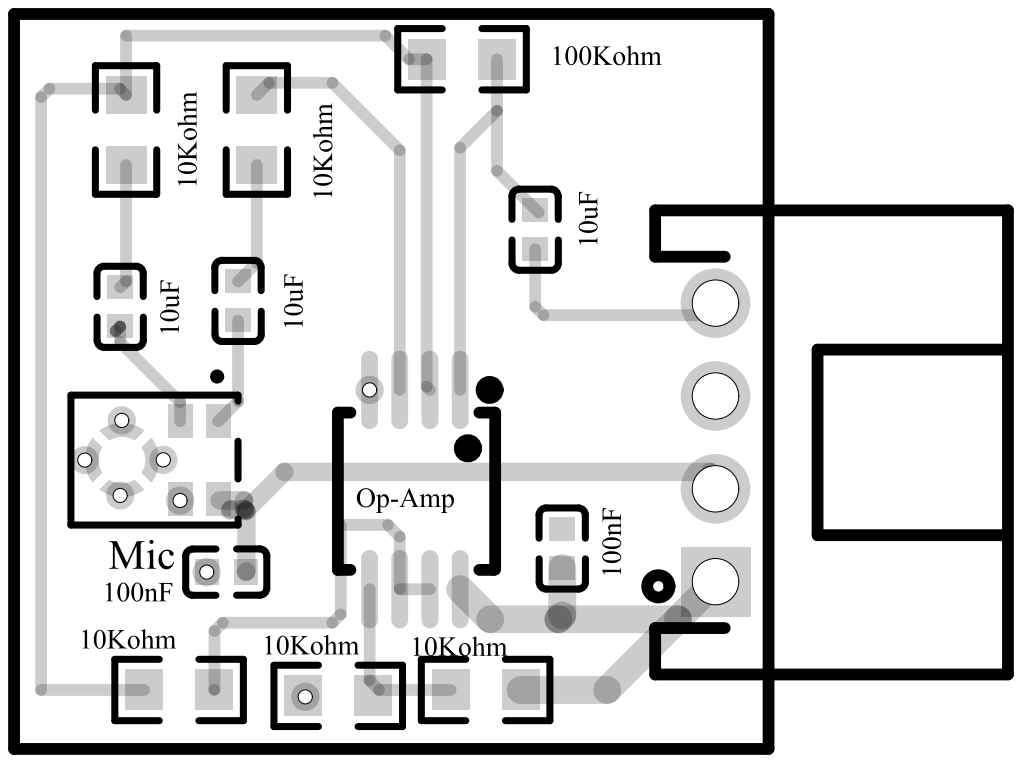
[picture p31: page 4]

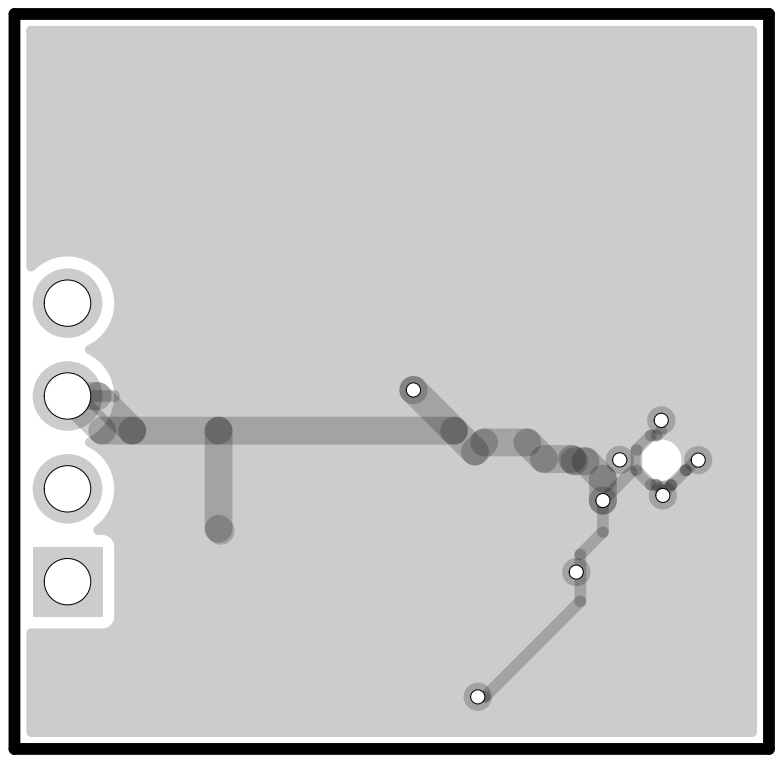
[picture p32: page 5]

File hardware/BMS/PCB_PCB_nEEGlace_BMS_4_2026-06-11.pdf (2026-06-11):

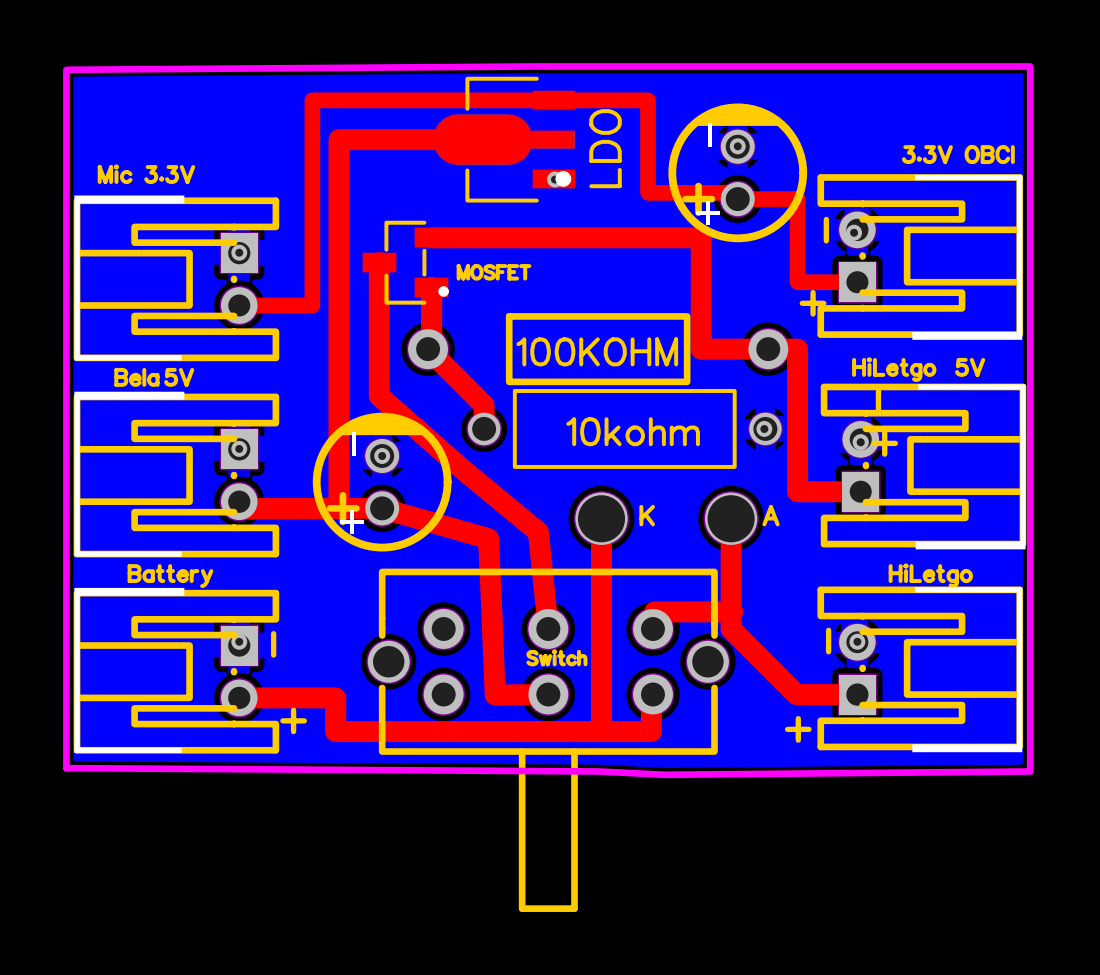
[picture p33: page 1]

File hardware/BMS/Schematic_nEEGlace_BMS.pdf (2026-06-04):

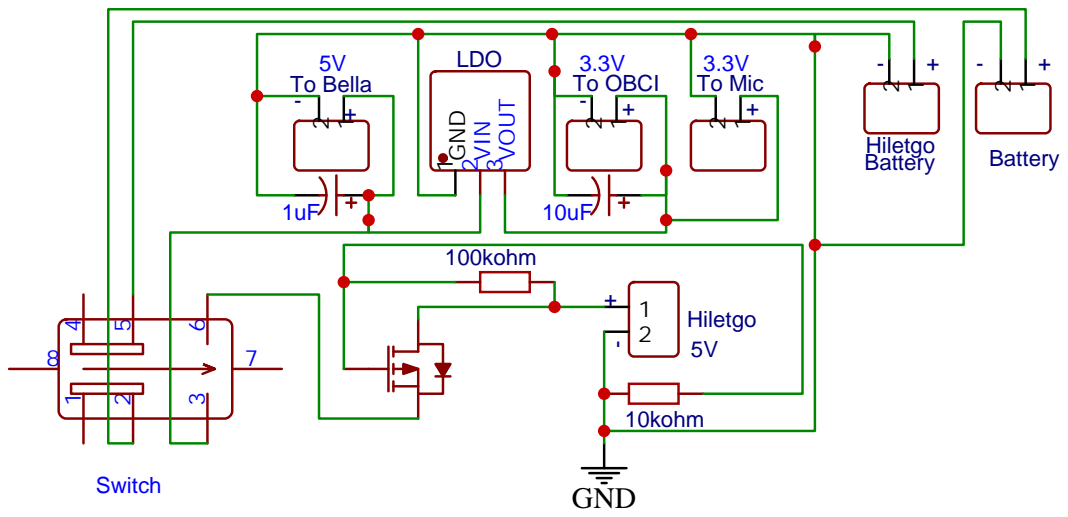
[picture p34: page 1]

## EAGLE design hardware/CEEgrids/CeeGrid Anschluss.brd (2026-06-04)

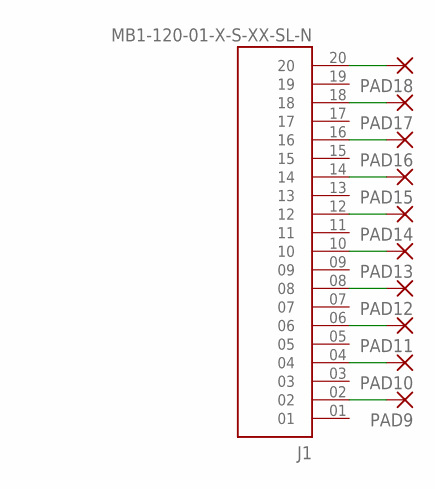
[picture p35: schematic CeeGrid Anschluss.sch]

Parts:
J1: MB1-120-01-X-S-XX-SL-N; SAMTEC_MB1-120-01-X-S-XX-SL-N
PAD9, PAD10, PAD11, PAD12, PAD13, PAD14, PAD15, PAD16, PAD17, PAD18: SMD2; SMD1,27-2,54

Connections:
unnamed: J1.20, PAD18.1
unnamed: J1.18, PAD17.1
unnamed: J1.16, PAD16.1
unnamed: J1.14, PAD15.1
unnamed: J1.12, PAD14.1
unnamed: J1.10, PAD13.1
unnamed: J1.08, PAD12.1
unnamed: J1.06, PAD11.1
unnamed: J1.04, PAD10.1
unnamed: J1.02, PAD9.1

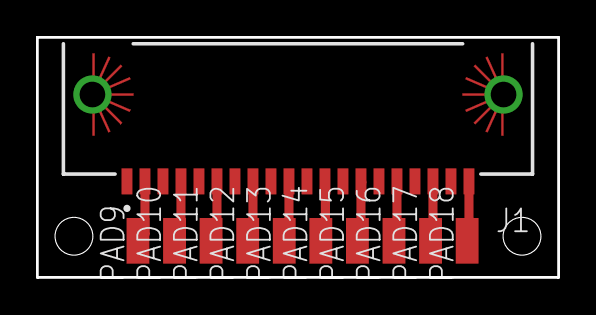
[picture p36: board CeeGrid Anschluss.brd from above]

Board: 2 copper layers, 29.0 x 13.3 mm, 11 parts (0 on the bottom side), 10 nets.

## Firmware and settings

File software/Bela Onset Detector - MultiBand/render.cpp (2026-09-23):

#include <Bela.h>
#include <cmath>
#include <vector>
#include <iostream>
#include <iomanip>
#include <fstream>
#include <string>
#include <sstream>
#include <ctime>
#include <array>

#include <libraries/AudioFile/AudioFile.h>
#include <libraries/Scope/Scope.h>

#include "onsetdetector.h"
#include "startupLogger.h"
#include "computeFeatures.h"

Scope scope;

const std::string configFilename = "Config.txt";
const std::string logFile = "bela_startup_log.txt";

// configuration
float inputGain           = 43.0f;
float activationDuration  = 0.05f;
float refractoryPeriod    = 0.5f;
float toneFreq            = 200.0f;
double recordAudio        = 1;
double recordDuration     = 20.0;

bool fullspectrum = false; 

// onset detector
OnsetDetectorParams detectorParams;
OnsetDetector detector;

// digital pin activation
const int digitalPin = 0;
int activationDurSamples = 0;
int activationCounter = 0;
int refractoryPeriodSamples = 0;
int refractoryCounter = 0;
int timeSinceLastOnset = 0;

// audio recording
std::vector<std::vector<float>> audioRecorder;
std::vector<int> digitalPinRecorder;
std::string audioFilename;
std::string markerFilename;
unsigned int recordingFrames = 0;

// feature extraction
const int FFT_SIZE = 2048;
FeatureCalculator features(FFT_SIZE);
std::vector<float> audioBuffer(FFT_SIZE, 0.0f);
int audioBufferIndex = 0;
unsigned int audioBufferFilled = 0;
std::vector<float> featureWindow(FFT_SIZE, 0.0f);
// for feature extraction window
bool featurePending = false;
int featureDelayCounter = 0;
const int featureDelaySamples = FFT_SIZE + 128; 
struct PendingEvent {
    unsigned int onset_index;
    double onset_time;
};
PendingEvent pendingEvent;


// onset event logging
std::string csvFilename;
std::ofstream csvFile;
bool csvFileOpen = false;
unsigned int totalFrames = 0;
unsigned int onset_index = 0;

// event struct
struct OnsetEvent
{
    unsigned int onset_index;
    double onset_time;
    float rms;
    //float levelDb;
    float dominantFrequency;
    //float spectralCentroid;
    //float spectralEnergy;
    //float lowEnergy;
    //float midEnergy;
    //float highEnergy;

	std::array<float, FFT_SIZE / 2 + 1> magnitudes{};
};


// event buffer
std::vector<OnsetEvent> onsetBuffer;
const int MAX_ONSET_EVENTS = 1000;

// CSV logging
double lastLogTime = 0.0;
const double logInterval = 1.0;

// function to generate filename
std::string generateFilename(const std::string& logFile)
{
    std::ifstream file(logFile);
    if (!file.is_open())
    {
        std::cout << "Cannot open: " << logFile << std::endl;
        return "";
    }

    std::string line;
    std::string featureFilename;

    while (std::getline(file, line))
    {
        if (line.rfind("Feature File:", 0) == 0)
        {
            featureFilename =
                line.substr(std::string("Feature File:").length());

            // remove leading whitespace
            featureFilename.erase(0, featureFilename.find_first_not_of(" \t"));
            // remove trailing whitespace
            featureFilename.erase(featureFilename.find_last_not_of(" \t\r\n") + 1);
        }
    }

    std::cout<< "Feature filename found: ["<< featureFilename<< "]"<< std::endl;
    return featureFilename;
}


// read configuration file
bool readConfig(const std::string& filename)
{
    std::ifstream f(filename);

    if (!f.is_open())
    {
        rt_printf("Cannot open config file — using defaults.\n");
        return false;
    }

    std::string line;

    while (std::getline(f, line))
    {
        std::istringstream iss(line);
        std::string key;
		
        if (!(iss >> key))
            continue;

        if (key == "inputGain")
        {
            iss >> inputGain;
        }

        else if (key == "activationDuration")
        {
            iss >> activationDuration;
        }

        else if (key == "refractoryPeriod")
        {
            iss >> refractoryPeriod;
        }

        else if (key == "toneFreq")
        {
            iss >> toneFreq;
        }

        else if (key == "recordAudio")
        {
            iss >> recordAudio;
        }

        else if (key == "recordDuration")
        {
            iss >> recordDuration;
        }

        else if (key == "svf_cutoff_Hz")
        {
            iss >> detectorParams.svf_cutoff_Hz;
        }

        else if (key == "svf_Q")
        {
            iss >> detectorParams.svf_Q;
        }

        else if (key == "threshBase")
        {
            for (int i = 0; i < 4; ++i)
                iss >> detectorParams.threshBase[i];
        }

        else if (key == "jumpFactor")
        {
            for (int i = 0; i < 4; ++i)
                iss >> detectorParams.jumpFactor[i];
        }

        else if (key == "decayConst")
        {
            for (int i = 0; i < 4; ++i)
                iss >> detectorParams.decayConst[i];
        }

        else if (key == "tauFast_ms")
        {
            for (int i = 0; i < 4; ++i)
                iss >> detectorParams.tauFast_ms[i];
        }

        else if (key == "tauSlow_ms")
        {
            for (int i = 0; i < 4; ++i)
                iss >> detectorParams.tauSlow_ms[i];
        }
    }

    f.close();

    return true;
}


void getFeatureWindow()
{
    if (audioBufferFilled < FFT_SIZE)
    {
        const int missing =
            FFT_SIZE - audioBufferFilled;

        // zero-pad the beginning
        for (int i = 0; i < missing; ++i)
            featureWindow[i] = 0.0f;

        // copy available samples
        for (unsigned int i = 0; i < audioBufferFilled; ++i)
        {
            int index = (audioBufferIndex - static_cast<int>(audioBufferFilled) + static_cast<int>(i)) % FFT_SIZE;
            if (index < 0)
                index += FFT_SIZE;
			
            featureWindow[missing + i] = audioBuffer[index];
        }
    }

    else
    {
        // buffer is full.
        for (int i = 0; i < FFT_SIZE; ++i)
        {
            int index = (audioBufferIndex + i) % FFT_SIZE;
            featureWindow[i] = audioBuffer[index];
        }
    }
}


// log onset events to CSV
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

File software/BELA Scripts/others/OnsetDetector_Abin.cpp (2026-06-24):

/**
 * Audio onset detection using energy and spectral features
 * ---------------------------------------------------------
 * Optimized version with logging every second.
 * No real-time I/O in render(). Underruns avoided.
 */

#include <Bela.h>
#include <cmath>
#include <vector>
#include <iostream>
#include <fstream>
#include <iomanip>
#include <string>
#include <sstream>
#include <libraries/AudioFile/AudioFile.h>
#include <libraries/Biquad/Biquad.h>
#include <algorithm>
#include <ctime>
#include <libraries/Scope/Scope.h>
#include <fftw3.h>  // Required for FFT

// Crate a scope object with 2 channels to visualize the audio signal
Scope scope;

// Define the configuration file name
const std::string configFilename = "config.txt"; 

// Define the configuration parameters
int bufferSize = 512;                           // Number of samples stored in buffer for energy calculation
int hopSize = 256;                              // Interval at which buffer is processed
float refractoryPeriod = 0.2;                  // Refractory period (sec) - time between onset detections
float activationDuration = 0.5;               // Duration to activate the digital output pin after onset detection (sec)
float inputGain = 20;                          // Input gain for the microphones    
float energyThreshold = 0.001;                  // Threshold for detecting an onset
float toneFreq = 200.0;                        // Frequency of the tone to be generated

// Define state variables to keep track of the audio processing
std::vector<float> audioBuffer(bufferSize, 0.0f); // Buffer to store audio samples
int bufferIndex = 0;                           // Current position in audioBuffer
int hopCounter = 0;                            // Counter to track samples processed since last energy calculation 
int refractoryPeriodSamples;                   // Refractory period in samples
int refractoryCounter = 0;                     // Counter to track refractory period
int timeSinceLastOnset = 0;                    // Counter to track samples since last onset
int activationDurationSamples;                 // Activation duration in samples
int activationCounter = 0;                     // Counter to track how long digital output is activated
const int digitalPin = 0;                      // Digital pin number to activate

// Define variables for recording audio
std::vector<std::vector<float>> audioRecorder;  // Buffer to save audio
std::string audioFilename;                     // Filename to save audio
std::vector<int> digitalPinRecorder;           // Buffer to save digital pin states
std::string markerFilename;                    // Filename to save markers
double recordAudio = 0;                        // Flag to enable or disable audio recording
double recordDuration = 20;                    // Recording duration in seconds
unsigned int recordingFrames = 0;              // Counter to track frames recorded
const int RECORD_BUFFER_SIZE = 512;           // Define the buffer size for audio recording

// for adaptive thresholding
float fastLevelDb=-100.0f;
float slowLevelDb=-100.0f;

float fastAlpha = 0.3f;    // reacts quickly to onsets
float slowAlpha = 0.01f;  //tracks background slowly

float onsetThresholdDb = 4.0f; //more sensitive
//float onsetThresholdDb = 8.0f; //onset if fast level is 8 dB above slow level0
//float onsetThresholdDb = 12.0f; //much stricter

// Define the record buffer
std::vector<float> recordBuffer;
int recordBufferIndex = 0;

// Define variables for CSV logging
std::string csvFilename;
std::ofstream csvFile;
bool csvFileOpen = false;
unsigned int totalFrames = 0;

// Define a struct to store onset events
struct OnsetEvent {
    double timestamp;          // Timestamp of the onset event
    float energy;              // Energy of the onset event
    float rms;                 // RMS value of the onset event
    float freqContent;         // Frequency content of the onset event
	float levelDb;
	float onsetStrengthDb;
};

// Define a vector to store onset events
std::vector<OnsetEvent> onsetBuffer;
const int MAX_ONSET_EVENTS = 1000;             // Maximum number of onset events to store

// Define variables for logging every second
double lastLogTime = 0.0;                      // Last time we logged (in seconds)
const double logInterval = 1.0;                // Log every 1 second

// Define variables for FFT calculations
const int FFT_WINDOW_SIZE = 512;
fftwf_plan fftPlan;
std::vector<float> fftInput;
fftwf_complex* fftOutput = nullptr;

// Temporary buffers
std::vector<float> orderedBuffer;
std::vector<float> fftAnalysisWindow;


// Function to generate a unique filename (adds the current timestamp)
std::string generateFilename(const std::string& baseFilename) {
    // Get the current time
    std::time_t now = std::time(nullptr);
    char timestamp[20];
    std::strftime(timestamp, sizeof(timestamp), "%Y%m%d_%H%M%S", std::localtime(&now));
    // Return the base filename with the timestamp appended
    return baseFilename + "_" + timestamp;
}
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

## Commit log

2026-04-15 Revise Readme.md for BMS project clarity
    Updated the Readme.md to enhance clarity and detail about the Battery Management System (BMS) for the nEEGlace wearable EEG platform, including system description, power architecture, safety features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
2026-05-05 Added fft computation and README
    Implementation of an FFT calculation to display the frequency of the detected signal. Calculation performed using a circular buffer, with no data stored in the render function. The circular buffer is flushed every second. Revision and expansion of comments to improve readability. Addition of a README.txt file to aid in understanding the code.
    The issue with the recording duration persists. Currently, it cannot be set to more than 300 seconds. This is due to suboptimal memory usage when saving the audio file. This is still being worked on.
    [onset_detection_rms_csv_fft_ringbuffer_everysecond_03.cpp]
2026-05-12 Writing constantly to .csv file
    Thats Abins work
    [audio_features_20260508_124022.csv, config.txt]
2026-05-28 Add README for audio event detection implementation
    Added README.md for audio event detection code, detailing implementation, parameters, outputs, current status, limitations, and future improvements.
2026-06-04 Rename hardware/Samtec_PCB_3d.stl to hardware/3d files/Samtec_PCB_3d.stl
    [Samtec_PCB_3d.stl]
2026-06-04 Rename Schematic_nEEGlace_BMS_2026-05-28 (1).pdf to Schematic_nEEGlace_BMS.pdf
2026-06-04 Rename hardware/BOM_Schematic1_Bela_Gem_Stereo_2026-06-04.csv to hardware/Bela Cape/PCB_Assembly_Files/BOM_Bela_Gem_Stereo.csv
    [BOM_Bela_Gem_Stereo.csv, BOM_Schematic1_Bela_Gem_Stereo_2026-06-04.csv]
2026-06-04 Add BOM_Bela_Cape.csv to PCB assembly files
    [BOM_Bela_Cape.csv]
2026-06-04 Rename hardware/CeeGrid Anschluss.brd to hardware/CEEgrids/CeeGrid Anschluss.brd
    [CeeGrid Anschluss.brd]
2026-06-04 Rename hardware/CeeGrid Anschluss.sch to hardware/CEEgrids/CeeGrid Anschluss.sch
    [CeeGrid Anschluss.sch]
2026-06-11 Rename hardware/BMS/BOM_nEEGlace_BMS.csv to hardware/BMS/Assemble files/BOM_nEEGlace_BMS.csv
    [BOM_nEEGlace_BMS.csv]
2026-06-11 Rename PickAndPlace_PCB_nEEGlace_BMS.csv file
    [PickAndPlace_PCB_nEEGlace_BMS.csv]
2026-06-23 Rename hardware/CEEgrids/BOM_CEEgrids.csv to hardware/CEEgrids/Assembly files/BOM_CEEgrids.csv
    [BOM_CEEgrids.csv]
2026-06-23 Rename hardware/CEEgrids/PickAndPlace_CeeGrid.csv to hardware/CEEgrids/Assembly Files/PickAndPlace_CeeGrid.csv
    [PickAndPlace_CeeGrid.csv]
2026-06-23 Rename hardware/MIC/BOM_Mic_PCB.csv to hardware/MIC/Assembly files/BOM_Mic_PCB.csv
    [BOM_Mic_PCB.csv]
2026-06-23 Rename hardware/MIC/odb++_Mic_PCB.tgz to hardware/MIC/Assembly file/odb++_Mic_PCB.tgz
2026-06-23 Rename hardware/MIC/PickAndPlace_Mic_PCB.csv to hardware/MIC/Assembly files/PickAndPlace_Mic_PCB.csv
    [PickAndPlace_Mic_PCB.csv]
2026-06-23 Rename hardware/Connector_PCB/BOM_Schematic3_Connector_PCB_2026-06-12.csv to hardware/Connector_PCB/Assembly files/BOM_Schematic3_Connector_PCB_2026-06-12.csv
    [BOM_Schematic3_Connector_PCB_2026-06-12.csv]
2026-06-23 Add PickAndPlace_Connector_PCB.csv file
    [PickAndPlace_Connector_PCB.csv]
2026-06-23 Rename hardware/Connector_PCB/odb++_pcb_Connector.tgz to hardware/Connector_PCB/Assembly files/odb++_pcb_Connector.tgz
2026-06-23 Create README for CeeGrid Anschluss PCB
    Added documentation for the CeeGrid Anschluss PCB, detailing its purpose, structure, and usage.
2026-07-20 Rename hardware/nEEGlace_Preassembled PCBs_Guide.pdf to hardware/Documents/nEEGlace_Preassembled PCBs_Guide.pdf
2026-07-21 Fix link formatting for Li-ion battery reference
    Updated link format for the Li-ion battery reference in the hardware components section.
2026-08-31 Deleting old versions
    [3D_Mic.step, BOM_Mic_PCB.csv, PickAndPlace_Mic_PCB.csv]
2026-08-31 Rename hardware/MIC/PickAndPlace__Mic.csv to hardware/MIC/Assembly Files/PickAndPlace__Mic.csv
    [PickAndPlace__Mic.csv]
